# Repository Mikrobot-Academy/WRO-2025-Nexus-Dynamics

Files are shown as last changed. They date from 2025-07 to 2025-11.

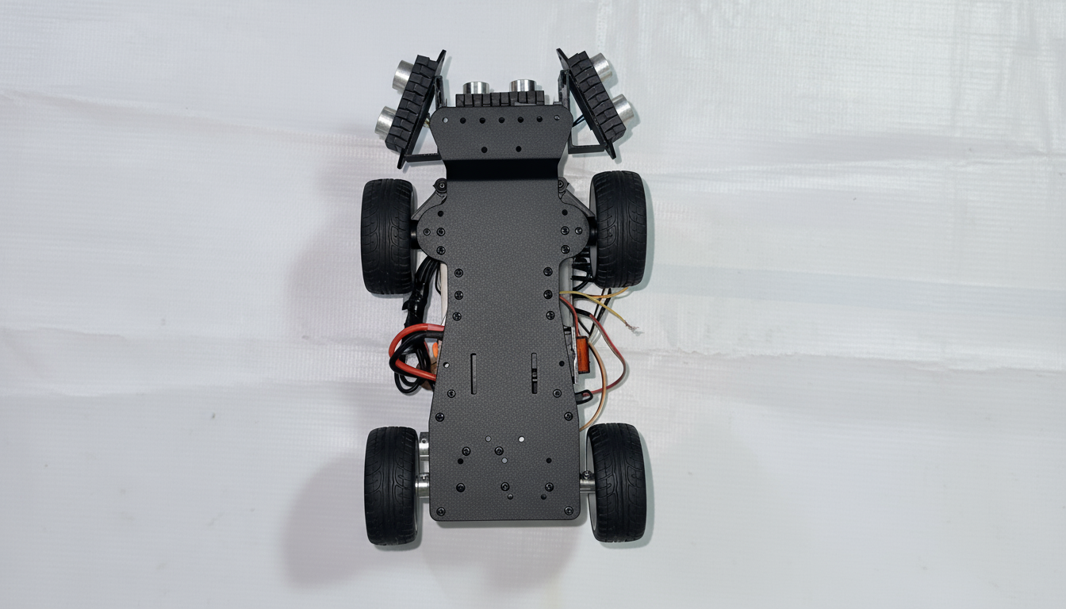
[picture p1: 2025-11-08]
v-photos/Bottom.png

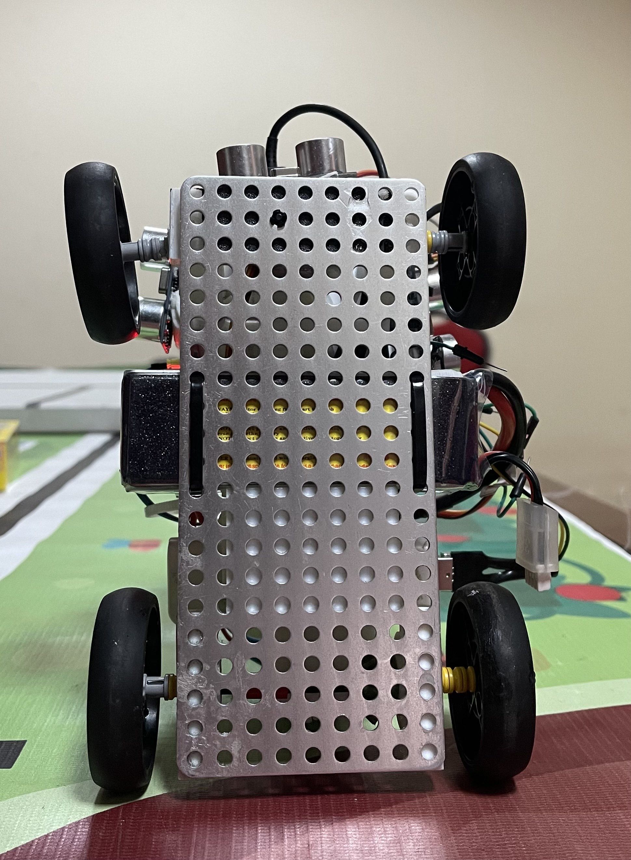
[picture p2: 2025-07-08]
v-photos/Bottom.jpg

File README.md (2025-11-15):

Team  NEXUS DYNAMICS – WRO 2025 Future Engineers
===========================================
Welcome to the official repository of Team NEXUS DYANMICS, proudly representing Mikrobot Academy from Ghana in the WRO 2025 Future Engineers category.

                   

## Overview of our repository 📜
* `schemes`- contains the circuit diagram.
* `models` - includes all the 3d printed parts of the robot.
* `others`-  This is for other files which can be used to understand the making of the vehicle. 
* `src` - the codes for both challenges.
* `t-photos` - photos of the team one formal and a funny one.
* `v-photos` - photos of the robot.
* `video` - the link to our youtube channel where you can see our robot in action completing both challenges.
* `README.md` - Here's all our journey in the development of our robot here we explain every part of the robot making.

## Components 🧱
A list of all the electrical and mechanical components in the robot.

|  |  |  |
| :---: | :---: | :---: |
| [Raspberry Pi 5 x1](https://www.raspberrypi.com/products/raspberry-pi-5/) | [L298N Motor Driver x1](https://www.daakyetech.com/store/l298n-motor-driver-board-v1/) | [HC-SR04 x3](https://www.sparkfun.com/ultrasonic-distance-sensor-hc-sr04.html) |

|  |  |  |
| :---: | :---: | :---: |
| [25GA-370 Gear Motor x1](https://www.okuelectronics.com/store/motors-pumps/25ga-370-gear-motor-12v-250rpm-with-4mm-shaft/) | [MG-996R Servo x1](https://www.okuelectronics.com/store/motors-pumps/servo-mg996r-13kg-360-degree-high-quality/) | [Power Bank x1](https://www.jumia.com.gh/oraimo-power-bank-10000mah-toast-22.5-byte-22.5w-black-290664811.html) |

|  |  |  |
| :---: | :---: | :---: |
| [LiPo Battery x1](https://www.hobbyrc.co.uk/gnb-2200mah-3s-110c-lipo-battery) | [Push Button x1](https://www.chinadaier.com/kd4-21-dpst-push-button-switch/) | [Jumper Wires x24](https://www.daakyetech.com/store/jumper-wires-40-20/) |

<br></br>

---
## Circuit Diagram
<p align=center>
  Circuit Diagram
</p>

This circuit diagram represents the connections of our robotic system.

<br></br>
---

## Robot Photos 📸
| Top | Right | Front
| :---: | :---: | :---: |
| Top | Right | Front |
| Left | Back| Bottom |
| Left | Back | Bottom |

<br></br>
---

## Raspberry Pi Robot Code Explanation (Open Challenge)

---

### Library Imports & GPIO Mode

```python
import RPi.GPIO as GPIO
import time

GPIO.setmode(GPIO.BCM)
GPIO.setwarnings(False)
```

- `RPi.GPIO` lets the Raspberry Pi communicate with motors, servos, sensors, etc.
- `time` is used for delays while reading sensors and controlling motors.
- `GPIO.setmode(GPIO.BCM)` uses the GPIO pin numbering based on the Broadcom chip, not physical pin numbers.
- `GPIO.setwarnings(False)` hides warnings if GPIO was used before.

---

### Button Setup (to select mode)

```python
BUTTON_PIN = 12
GPIO.setup(BUTTON_PIN, GPIO.IN, pull_up_down=GPIO.PUD_DOWN)
```

- Button is connected to GPIO 12
- Internal resistor is set to Pull-Down → button reads 0 until pressed

---

### Two Main Modes

| Code Function | Wall followed | Sensor pins | PID Tuning | Speed Setting |
|---|---|---|---|---|
| `run_right_wall()` | Right wall | TRIG=7, ECHO=16 | Kd = 0.2 | 75% |
| `run_left_wall()` | Left wall | TRIG=25, ECHO=8 | Kd = 0.4 | 65% |

Different tuning because:
- Sensor placement and servo direction are opposite each side
- Gives smoother driving when tuned separately

---

### Ultrasonic Distance Measurement

```python
def read_distance():
    GPIO.output(TRIG, False)
    time.sleep(0.00001)
    GPIO.output(TRIG, True)
    time.sleep(0.00001)
    GPIO.output(TRIG, False)

    # Echo timing calculation here...
    duration = pulse_end - pulse_start
    distance = round(duration * 17150, 2)
```

- Calculates distance using time of sound returning
- `distance (cm) = duration × 17150`
- Returns `None` if ultrasonic reading fails

Used for detecting walls and corners.

---

### PID Steering Control

```python
Kp, Ki, Kd = 6, 0, 0.2
error = setpoint - d
correction = Kp*error + Ki*integral + Kd*derivative
servo_angle = 90 + correction
```

- Target distance from wall = 20 cm
- Too far → turn towards the wall
- Too close → turn away

Servo movement limits:

```python
angle = max(60, min(120, angle))
```

Prevents over-steering.

---

### Motor Control

```python
motor_pwm.ChangeDutyCycle(speed)
GPIO.output(IN1, True)
GPIO.output(IN2, False)
```

- PWM controls speed
- Direction pins choose forward/backward movement

Forward, stop, and corner manoeuvres controlled here.

---

### Corner Detection

```python
if d > 100 or d < 0:
    print("Wall lost, corner")
    approach_wall()
    corner_count += 1
```

- If no wall detected → robot guesses corner
- Turns and realigns with next wall
- Stops after max corners reached (full lap)

---

### Cleanup

```python
GPIO.cleanup()
```

- Releases GPIO pins cleanly
- Prevents Raspberry Pi crashes next time script runs

---

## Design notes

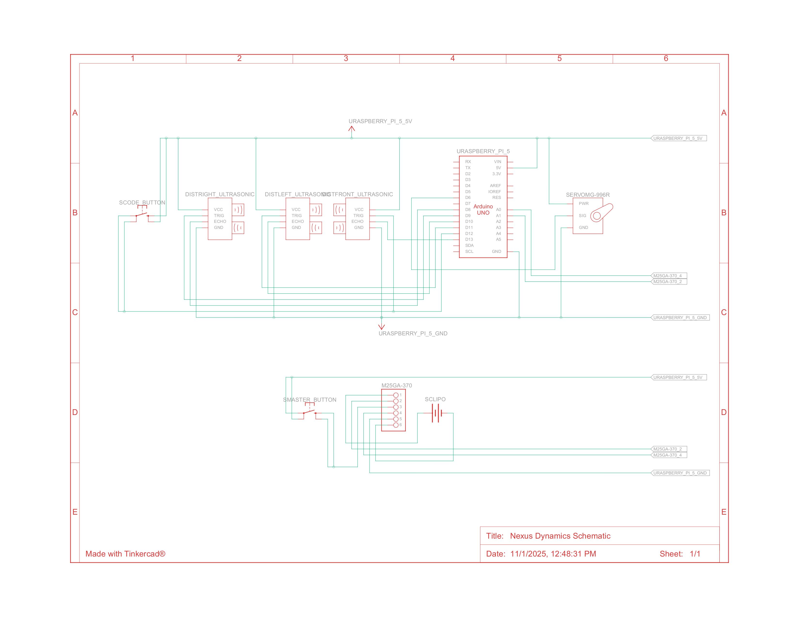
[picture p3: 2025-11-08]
schemes/Nexus Dynamics Schematic.jpg

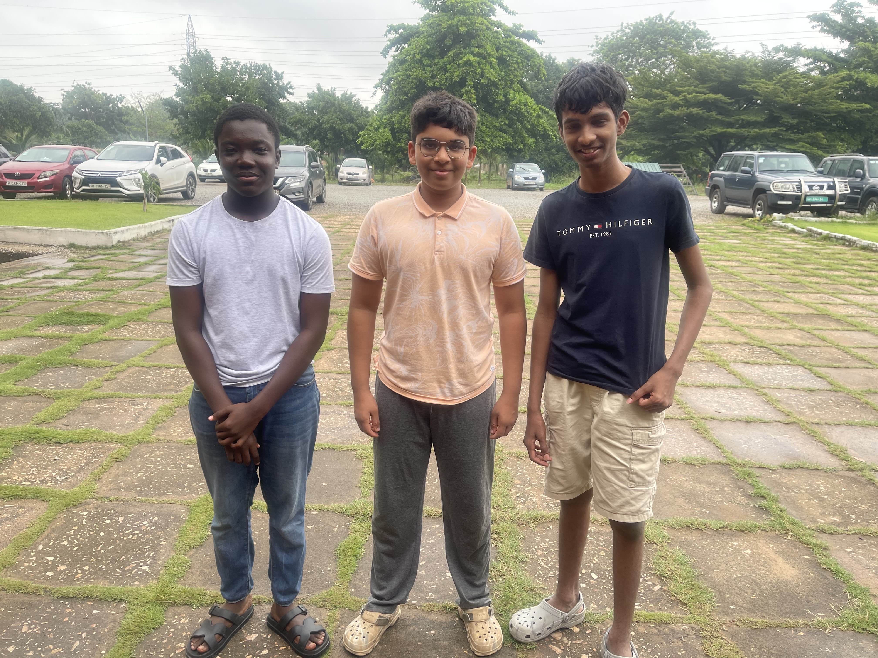
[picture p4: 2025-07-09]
t-photos/team photo.jpg

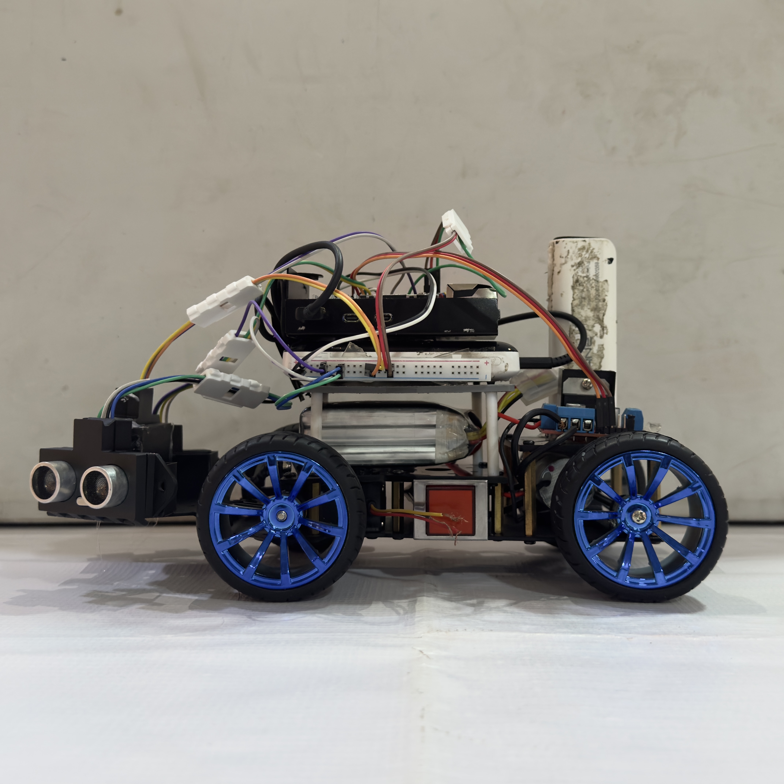
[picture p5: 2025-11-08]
v-photos/Left.jpg

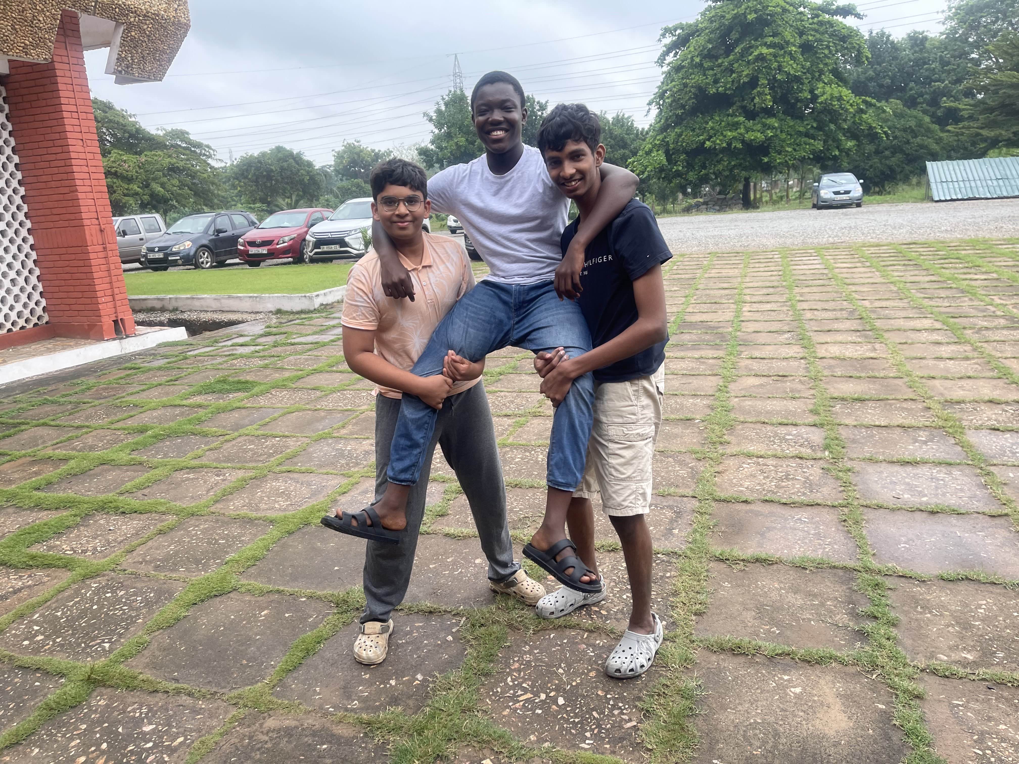
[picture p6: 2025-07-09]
t-photos/funny photo.jpg

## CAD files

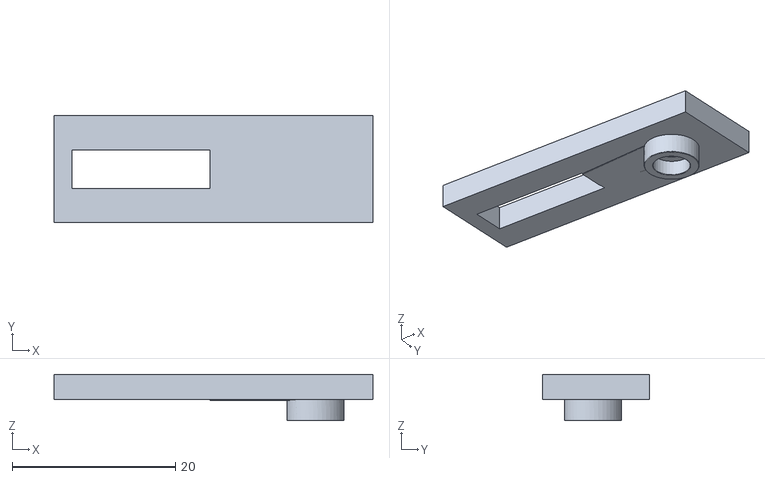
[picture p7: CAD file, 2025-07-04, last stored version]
models/Servo Horn.stl
39.0 x 13.1 x 5.68

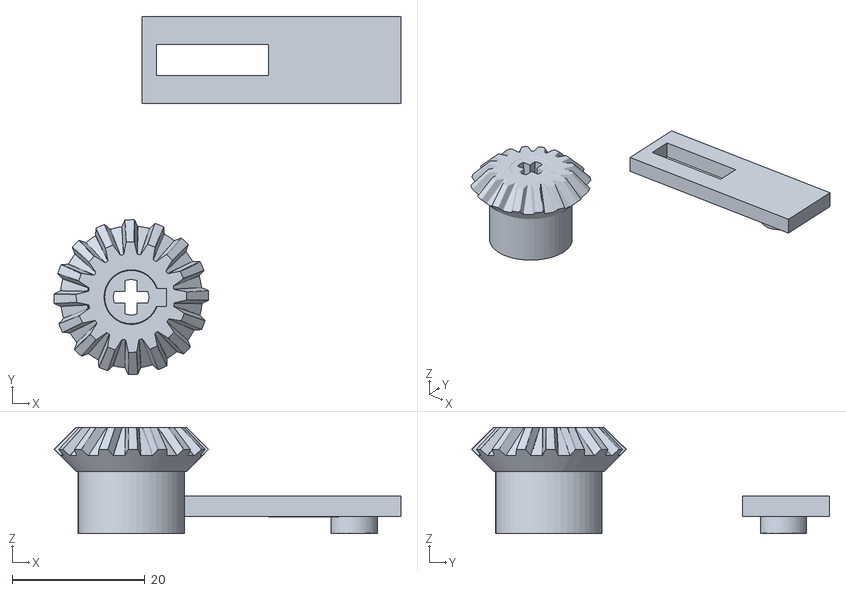
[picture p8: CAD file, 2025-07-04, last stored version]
models/Axle Gear.stl
52.3 x 54.0 x 16.1

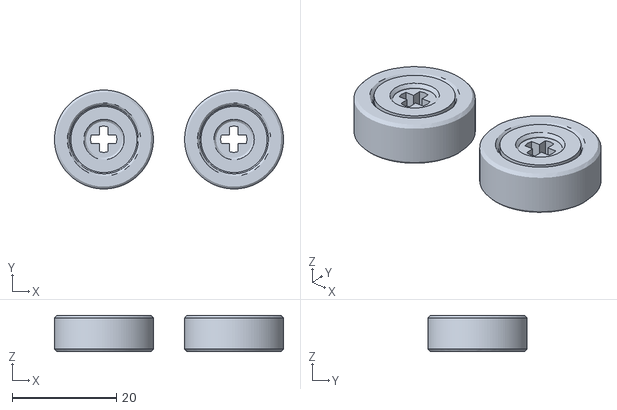
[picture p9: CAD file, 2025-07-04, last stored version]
models/Bearings.stl
44.0 x 19.0 x 7.00

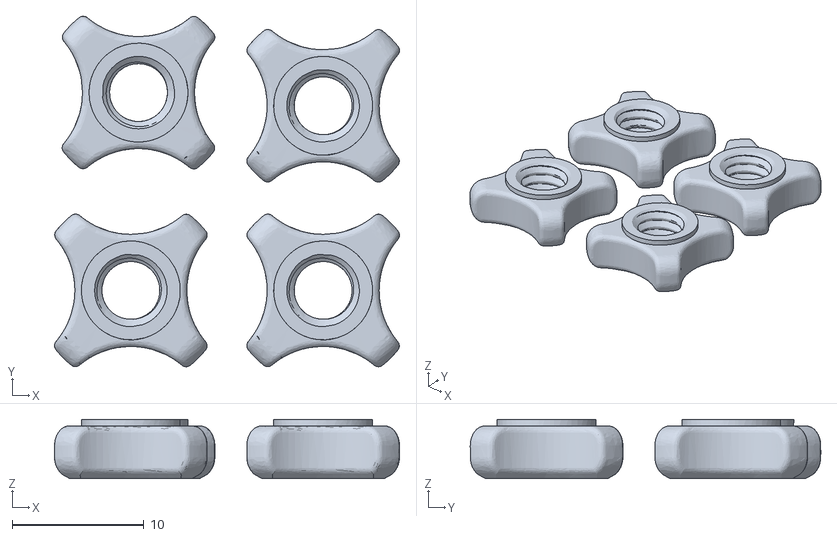
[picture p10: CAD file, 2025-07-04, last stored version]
models/Cam Plate Mounting Nuts.stl
26.2 x 26.6 x 4.50

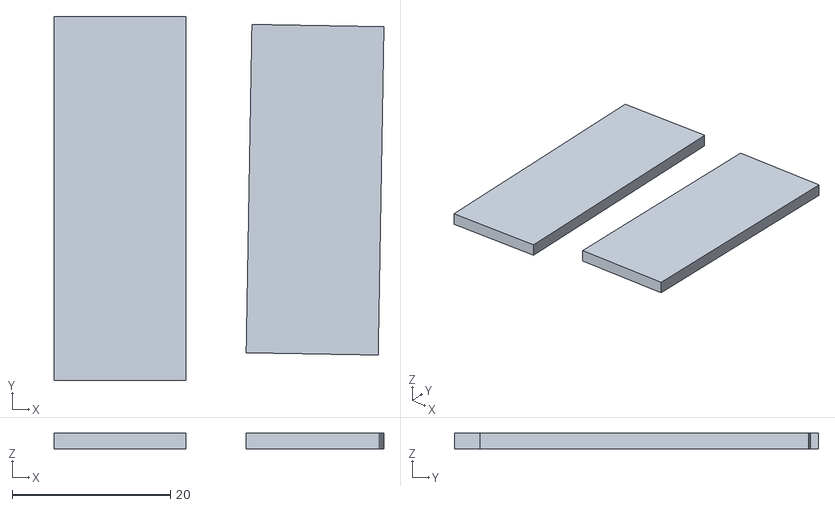
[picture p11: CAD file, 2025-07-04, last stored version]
models/Cam Plates.stl
41.7 x 46.0 x 2.00

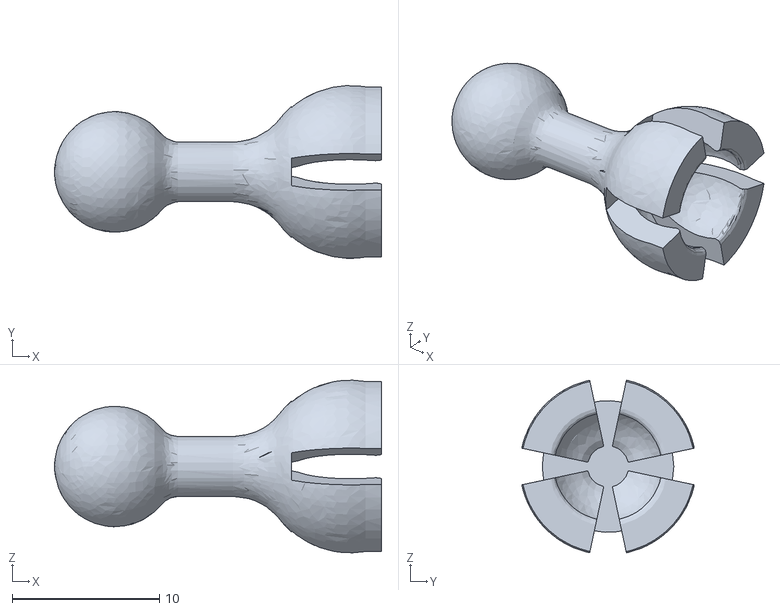
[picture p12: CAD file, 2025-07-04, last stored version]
models/Cam Mount - Middle Joint.stl
22.2 x 11.7 x 11.7

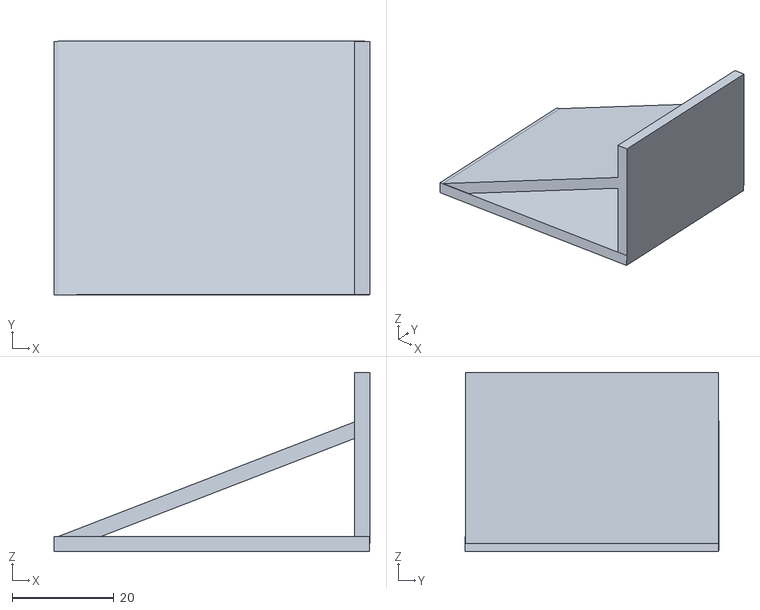
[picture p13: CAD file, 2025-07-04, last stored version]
models/Second Layer Support.stl
62.0 x 49.8 x 35.2

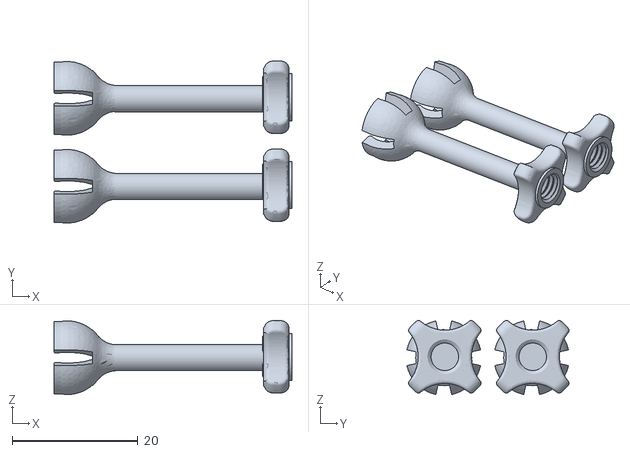
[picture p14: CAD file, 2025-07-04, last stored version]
models/Cam Mount - Top Joint.stl
37.9 x 25.8 x 11.8

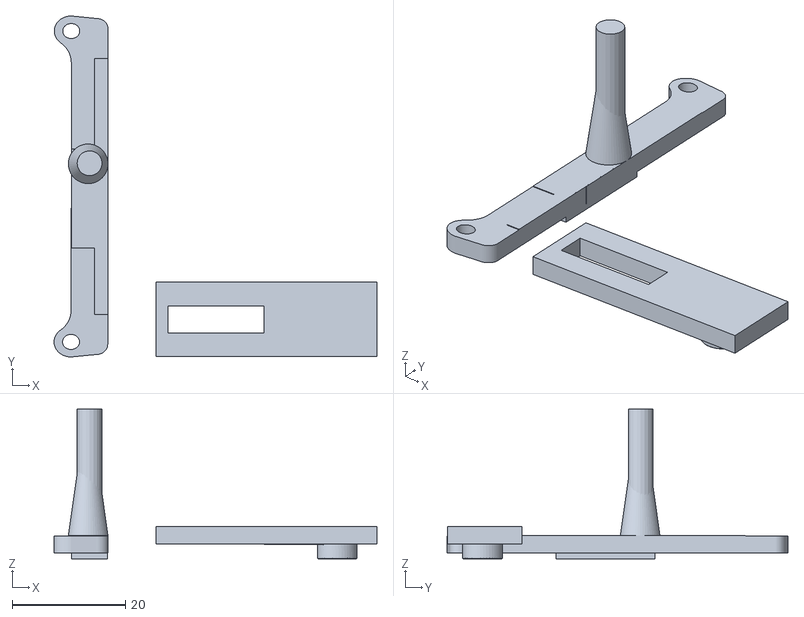
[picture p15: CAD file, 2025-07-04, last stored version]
models/Steering Mount.stl
57.0 x 60.2 x 26.4

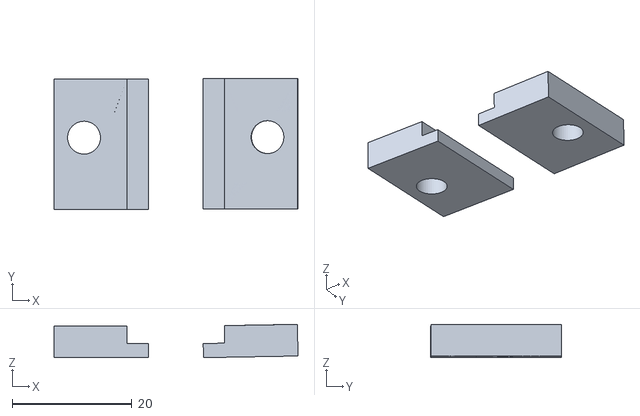
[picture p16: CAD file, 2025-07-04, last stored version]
models/Steering Locks.stl
40.8 x 22.0 x 5.57

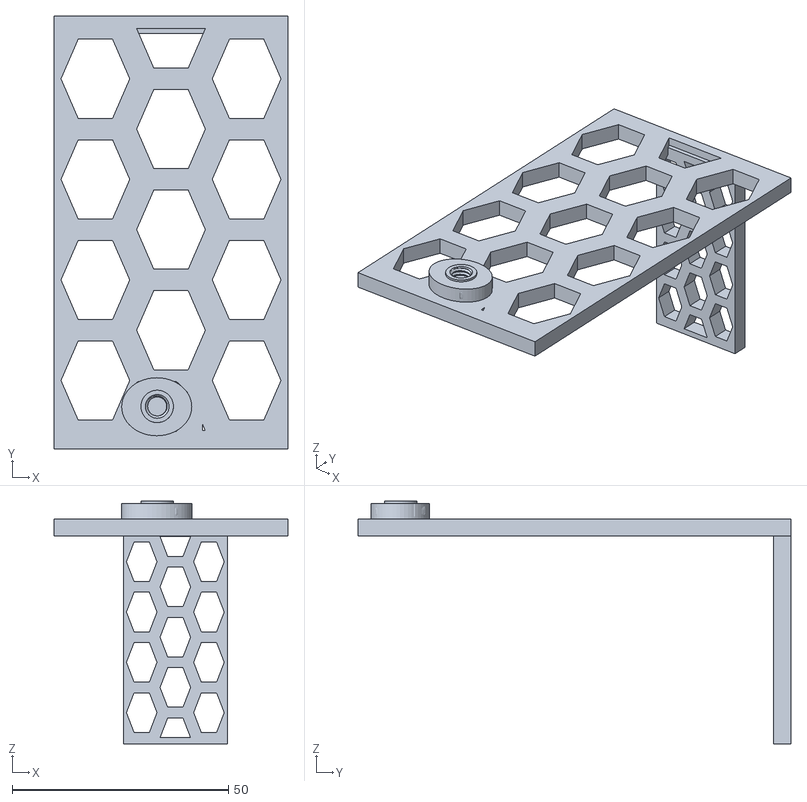
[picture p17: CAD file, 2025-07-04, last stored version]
models/Second Layer.stl
54.0 x 100.1 x 56.1

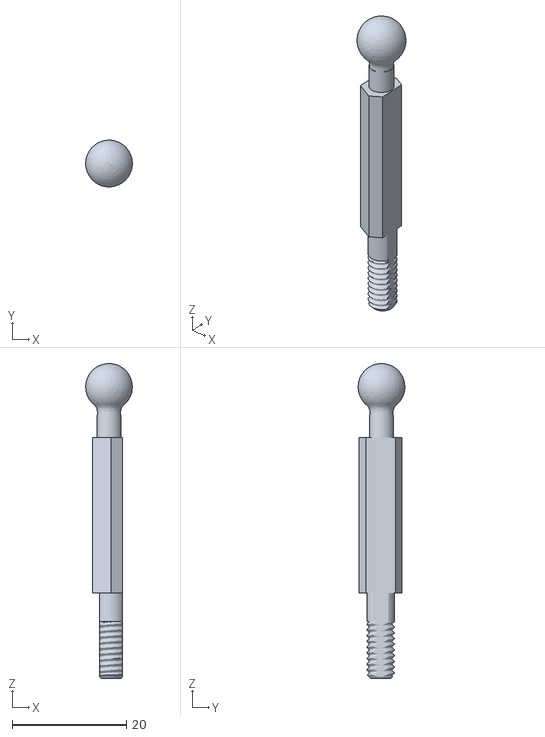
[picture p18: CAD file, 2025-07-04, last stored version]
models/Cam Mount - Base Joint.stl
8.19 x 8.19 x 55.1

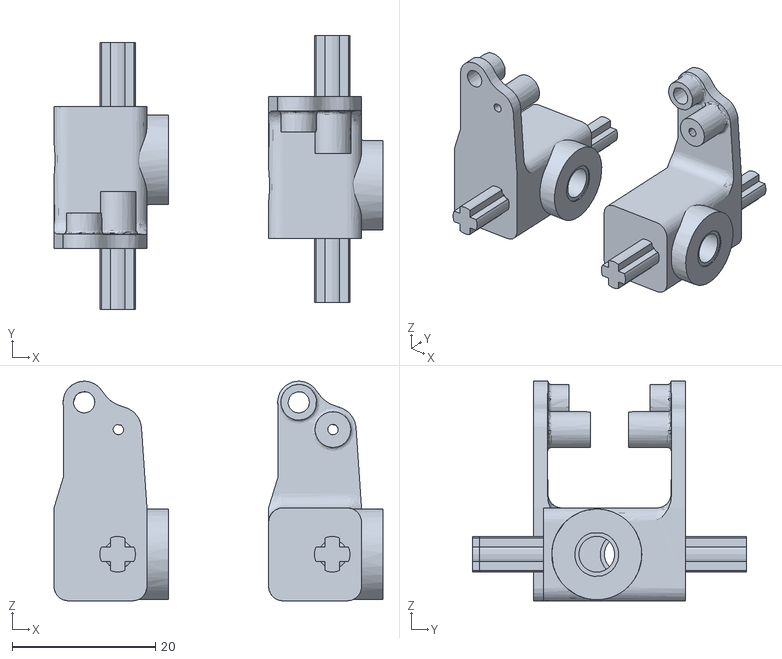
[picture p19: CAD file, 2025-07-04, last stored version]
models/Wheel Mounts.stl
46.0 x 38.3 x 30.7

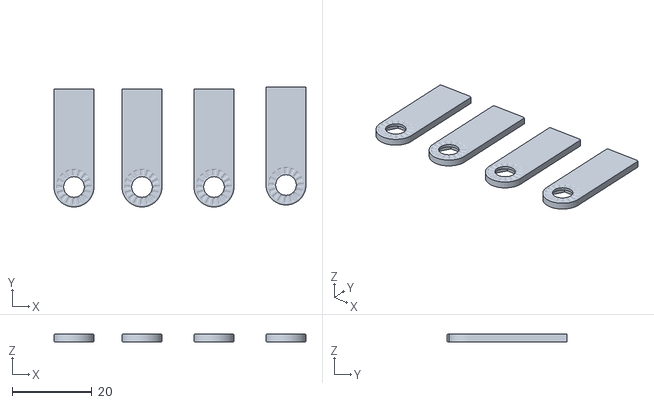
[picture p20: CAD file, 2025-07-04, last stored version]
models/Cam Plate Mounts.stl
63.0 x 30.0 x 2.00

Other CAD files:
models/Servo Mount.stl
models/Motor Gear.stl
models/Cam Mount Washers.stl

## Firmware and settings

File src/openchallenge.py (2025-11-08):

import RPi.GPIO as GPIO
import time

GPIO.setmode(GPIO.BCM)
GPIO.setwarnings(False)

BUTTON_PIN = 12
GPIO.setup(BUTTON_PIN, GPIO.IN, pull_up_down=GPIO.PUD_DOWN)

# ====================
# === RIGHT WALL (k.py)
# ====================
def run_right_wall():
    print("▶▶ Running RIGHT wall code...")

    # === GPIO SETUP ===
    TRIG = 23
    ECHO = 24
    SERVO_PIN = 18
    ENA = 22
    IN1 = 17
    IN2 = 27

    GPIO.setup(TRIG, GPIO.OUT)
    GPIO.setup(ECHO, GPIO.IN)
    GPIO.setup(SERVO_PIN, GPIO.OUT)
    GPIO.setup([ENA, IN1, IN2], GPIO.OUT)

    servo_pwm = GPIO.PWM(SERVO_PIN, 50)
    servo_pwm.start(7.5)
    motor_pwm = GPIO.PWM(ENA, 1000)
    motor_pwm.start(0)
    GPIO.output(IN1, True)
    GPIO.output(IN2, False)

    # PID constants
    Kp, Ki, Kd = 3.5, 0, 0.45
    setpoint = 35
    last_error, integral = 0, 0
    corner_count, max_corners = 0, 12

    def read_distance():
        GPIO.output(TRIG, False)
        time.sleep(0.00001)
        GPIO.output(TRIG, True)
        time.sleep(0.00001)
        GPIO.output(TRIG, False)
        start = time.perf_counter()
        timeout = start + 0.04
        pulse_start, pulse_end = None, None
        while GPIO.input(ECHO) == 0 and time.perf_counter() < timeout:
            pulse_start = time.perf_counter()
        while GPIO.input(ECHO) == 1 and time.perf_counter() < timeout:
            pulse_end = time.perf_counter()
        if pulse_start and pulse_end:
            duration = pulse_end - pulse_start
            distance = round(duration * 17150, 2)
            if distance <= 0: return -1
            if distance > 600: return None
            return distance
        return None

    def set_servo_angle(angle):
        angle = max(40, min(130, angle))
        duty = 2 + ((180-angle) / 18)
        servo_pwm.ChangeDutyCycle(duty)
        print(f"Servo → {angle:.2f}°")

    def stop_robot():
        motor_pwm.ChangeDutyCycle(0)
        GPIO.output(IN1, False)
        GPIO.output(IN2, False)
        set_servo_angle(90)
        print("🚦 Stopped")

    def start_robot(speed=90):
        motor_pwm.ChangeDutyCycle(speed)
        GPIO.output(IN1, True)
        GPIO.output(IN2, False)
        print(f"🚀 Forward {speed}")

    def approach_wall():
        set_servo_angle(40)
        start_robot(74)
        while True:
            d = read_distance()
            if d and d > 0 and d < 50:
                stop_robot()
                print(f"✅ Found wall {d:.2f}cm")
                break
            time.sleep(0.009)

    try:
        while corner_count < max_corners:
            d = read_distance()
            if d is None: continue
            if d > 70 or d < 0:
                start_time = time.perf_counter()
                stop_robot()
                print(f"⚠️ Wall lost, corner {corner_count+1}")
                approach_wall()
                elapsed = time.perf_counter() - start_time
                if elapsed > 0.36:
                    corner_count += 1
                    print(f"🔁 Corner {corner_count}/{max_corners}")
                last_error, integral = 0, 0
                continue
            error = setpoint - d
            integral += error
            derivative = error - last_error
            correction = Kp*error + Ki*integral + Kd*derivative
            servo_angle = 90 + correction
            set_servo_angle(servo_angle)
            start_robot()
            last_error = error
            time.sleep(0.02)
        stop_robot()
        print("🏁 Done 4 corners.")
    except KeyboardInterrupt:
        stop_robot()
    finally:
        servo_pwm.stop()
        motor_pwm.stop()

# ====================
# === LEFT WALL (antik.py)
# ====================
def run_left_wall():
    print("▶▶ Running LEFT wall code...")

    # === GPIO SETUP ===
    TRIG = 25
    ECHO = 8
    SERVO_PIN = 18
    ENA = 22
    IN1 = 17
    IN2 = 27

    GPIO.setup(TRIG, GPIO.OUT)
    GPIO.setup(ECHO, GPIO.IN)
    GPIO.setup(SERVO_PIN, GPIO.OUT)
    GPIO.setup([ENA, IN1, IN2], GPIO.OUT)

    servo_pwm = GPIO.PWM(SERVO_PIN, 50)
    servo_pwm.start(7.5)
    motor_pwm = GPIO.PWM(ENA, 1000)
    motor_pwm.start(0)
    GPIO.output(IN1, True)
    GPIO.output(IN2, False)

    # PID constants
    Kp, Ki, Kd = 6, 0, 0.4
    setpoint = 27
    last_error, integral = 0, 0
    corner_count, max_corners = 0, 12

    def read_distance():
        GPIO.output(TRIG, False)
        time.sleep(0.00001)
        GPIO.output(TRIG, True)
        time.sleep(0.00001)
        GPIO.output(TRIG, False)
        start = time.perf_counter()
        timeout = start + 0.04
        pulse_start, pulse_end = None, None
        while GPIO.input(ECHO) == 0 and time.perf_counter() < timeout:
            pulse_start = time.perf_counter()
        while GPIO.input(ECHO) == 1 and time.perf_counter() < timeout:
            pulse_end = time.perf_counter()
        if pulse_start and pulse_end:
            duration = pulse_end - pulse_start
            distance = round(duration * 17150, 2)
            if distance <= 0: return -1
            if distance > 600: return None
            return distance
        return None

    def set_servo_angle(angle):
        angle = max(60, min(120, angle))
        duty = 2 + ((180 - angle) / 18)  # inverted
        servo_pwm.ChangeDutyCycle(duty)
        print(f"Servo (inv) → {angle:.2f}°")

    def stop_robot():
        motor_pwm.ChangeDutyCycle(0)
        GPIO.output(IN1, False)
        GPIO.output(IN2, False)
        set_servo_angle(90)
        print("🚦 Stopped")

    def start_robot(speed=100):
        motor_pwm.ChangeDutyCycle(speed)
        GPIO.output(IN1, True)
        GPIO.output(IN2, False)
        print(f"🚀 Forward {speed}")

    def approach_wall():
        set_servo_angle(60)
        start_robot(60)
        while True:
            d = read_distance()
            if d and d > 0 and d < 50:
                stop_robot()
                print(f"✅ Found wall {d:.2f}cm")
                break
            time.sleep(0.02)
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

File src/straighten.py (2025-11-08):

import RPi.GPIO as GPIO
import time

SERVO_PIN = 18

GPIO.setmode(GPIO.BCM)
GPIO.setup(SERVO_PIN, GPIO.OUT)

pwm = GPIO.PWM(SERVO_PIN, 50)  # 50Hz for servo
pwm.start(0)

def set_angle(angle):
    # Clamp angle between 0 and 180
    angle = max(0, min(180, angle))
    duty = 2.5 + (angle / 180.0) * 10  # Map 0–180° to 2.5–12.5 duty cycle
    pwm.ChangeDutyCycle(duty)
    time.sleep(0.5)  # give servo time to move
    pwm.ChangeDutyCycle(0)  # stop signal to avoid jitter

try:
    print("Setting servo to straight (90°)...")
    set_angle(130)
    input("Press Enter to quit...")

finally:
    pwm.stop()
    GPIO.cleanup()

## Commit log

2025-07-04 Addition of 3d model
    [Axle Gear.stl, Bearings.stl, Cam Mount - Base Joint.stl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]
2025-07-10 Robot Assembly Guide
2025-07-10 Change in Schematics
2025-10-11 code to test ultrasonics
2025-10-11 code to straighten the servo on our robot
2025-11-01 Fix team name and update Raspberry Pi section
    Corrected team name formatting and added image for Raspberry Pi.
2025-11-01 Remove Photos and Circuit Diagram sections from README
    Removed the Photos section and Circuit Diagram from the README.
2025-11-01 Add circuit diagram to README
    Added a circuit diagram section to the README.
2025-11-01 Improve circuit diagram section in README
    Updated the circuit diagram image tag to include an alt attribute.
2025-11-01 Enhance README with Raspberry Pi robot code details
    Expanded the README to include detailed explanations of the Raspberry Pi robot code, covering library imports, button setup, modes, distance measurement, PID control, motor control, corner detection,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
2025-11-05 Change of schematic
2025-11-05 change of robot base
    [Axle Gear.stl, Bearings.stl, Cam Mount - Base Joint.stl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]
2025-11-15 Simplify mode selection section in README
    Removed button mode selection details from README.
